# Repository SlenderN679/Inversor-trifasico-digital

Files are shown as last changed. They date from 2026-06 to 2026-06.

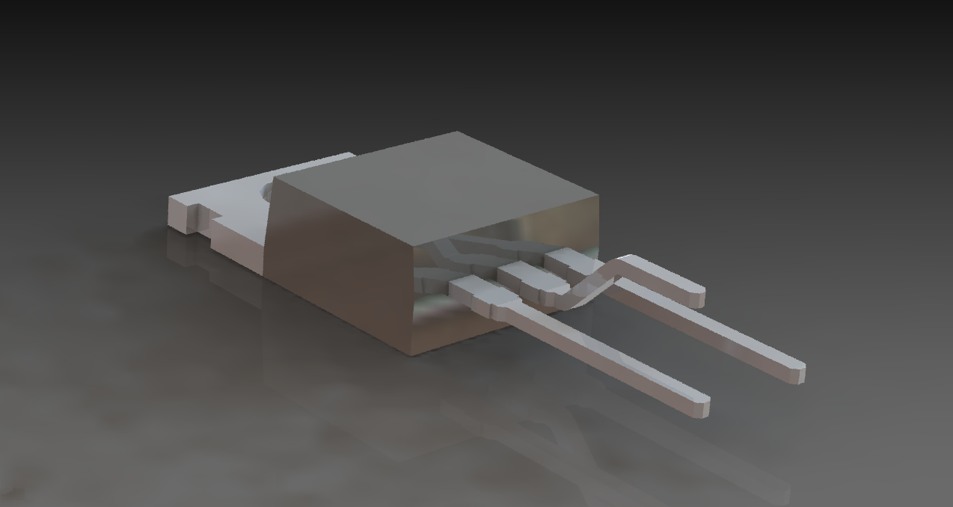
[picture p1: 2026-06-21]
Hardware/to-220-6.snapshot.1/5.PNG

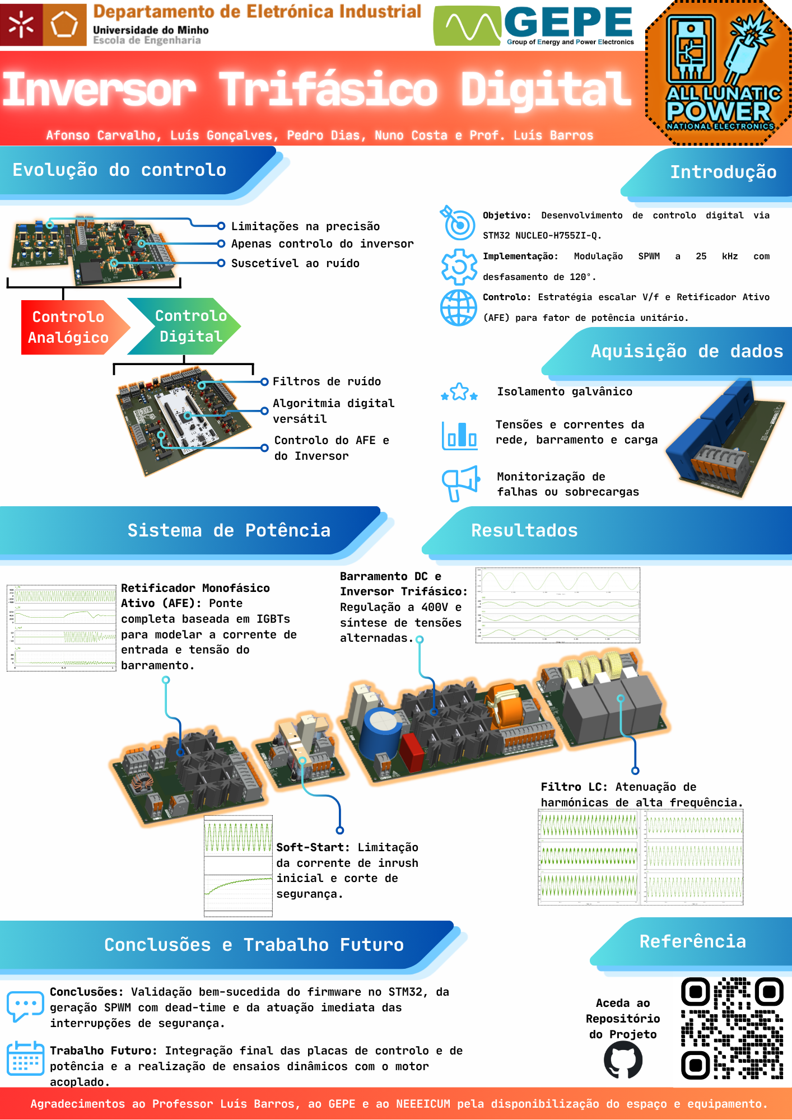
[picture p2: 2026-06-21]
Documentação/Poster.png

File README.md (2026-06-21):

# Inversor Trifásico com Controlo Digital ⚡





## 📌 Sobre o Projeto
Este repositório contém o firmware, o desenho de hardware e as simulações referentes ao desenvolvimento de um **Inversor Trifásico com Controlo Digital**, concebido no âmbito da disciplina de Projeto Integrador. 

O objetivo principal deste sistema é ultrapassar as limitações dos sistemas de controlo analógico (como a suscetibilidade ao ruído e restrições na precisão), transferindo a lógica de comutação e modulação para o domínio digital através de um microcontrolador **STM32 NUCLEO-H755ZI-Q**.

## ✨ Características Principais
* **Retificador Ativo (AFE):** Regulação de tensão num barramento de 400V DC com fator de potência unitário.
* **Inversor Trifásico:** Modulação por Largura de Pulso Sinusoidal (SPWM) operando a uma frequência de 25 kHz com injeção de *dead-time* por hardware.
* **Controlo de Motor:** Estratégia de controlo escalar (V/f constante) para regulação estável da velocidade angular.
* **Arranque Suave (Soft-Start):** Circuito de mitigação de correntes de *inrush* na pré-carga do barramento DC.
* **Telemetria:** Monitorização remota de dados (tensões, correntes e temperatura) via UART em formato JSON, integrada numa *dashboard* Node-RED.

## 📂 Estrutura do Repositório

| Diretório | Descrição |
| :--- | :--- |
| `Firmware/` | Código-fonte em C/C++ desenvolvido para o microcontrolador STM32H755ZI-Q (projeto STM32CubeIDE). |
| `Hardware/` | Ficheiros de desenho KiCad (esquemáticos, layout da PCB e ficheiros Gerber) das placas de controlo e potência. |
| `Simulacoes/` | Esquemas e testes dinâmicos criados no software PSIM para validação teórica dos blocos de potência. |
| `Telemetria/` | Ficheiros de configuração JSON para a interface gráfica no Node-RED. |
| `Documentacao/` | Relatório técnico completo, *datasheets* de componentes e o cartaz académico do projeto. |

## 🛠️ Tecnologias e Ferramentas Utilizadas
* **Hardware Digital:** Microcontrolador STMicroelectronics STM32 NUCLEO-H755ZI-Q.
* **Sensores e Isolamento:** Transdutores de corrente e tensão e *gate drivers* optoacoplados HCPL-3120.
* **Software/Ambientes:** STM32CubeIDE, KiCad EDA, PSIM, Node-RED.

## ⚠️ Aviso de Segurança
**PERIGO - ALTA TENSÃO:** Este projeto lida com tensões perigosas (entrada da rede elétrica e barramento DC de 400V). A replicação física e os testes na fase de potência requerem equipamento de proteção adequado e a supervisão de profissionais qualificados. Certifique-se de que os condensadores do barramento estão totalmente descarregados antes de manusear as placas.

## 👥 Equipa e Agradecimentos
**Desenvolvedores:** Afonso Carvalho, Pedro Dias, Luís Gonçalves e Nuno Costa.
**Orientação:** Prof. Luís Barros

Projeto desenvolvido com o apoio do **GEPE** (Grupo de Eletrónica de Potência e Energia) e do **NEEEICUM** (Núcleo de Estudantes de Engenharia Eletrónica Industrial e Computadores) da Universidade do Minho, Guimarães.

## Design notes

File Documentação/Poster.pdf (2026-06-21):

# Inversor Trifásico Digital

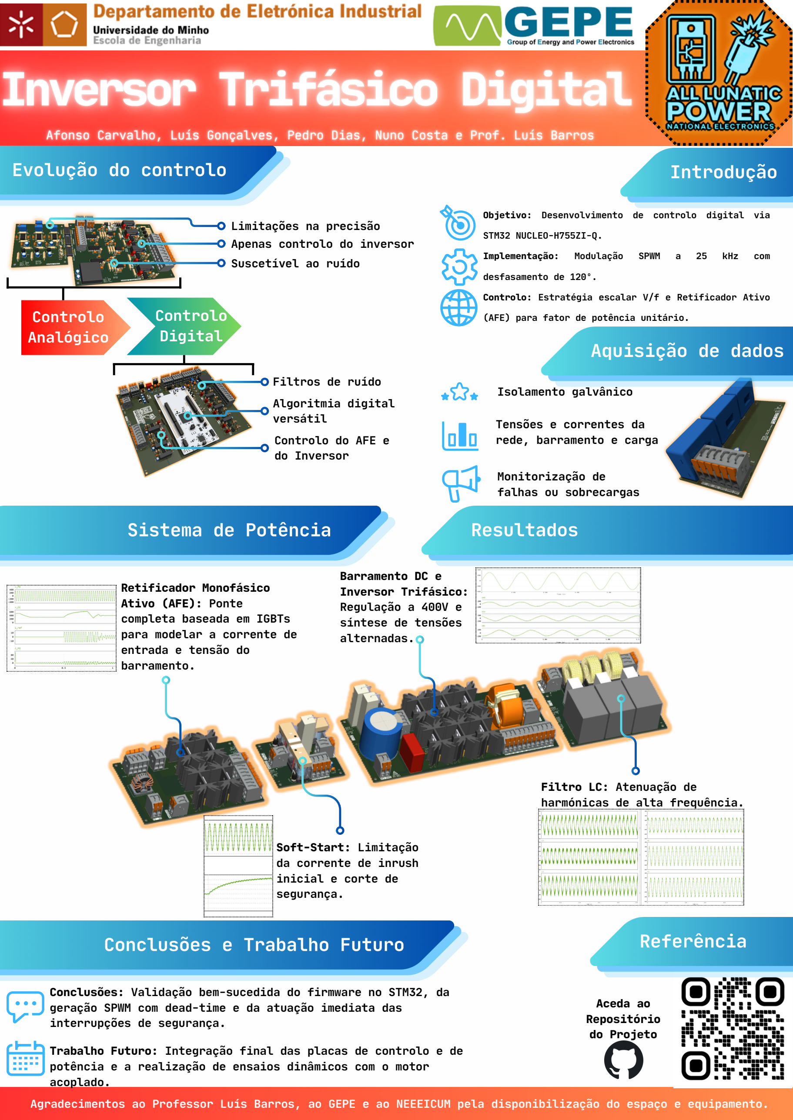
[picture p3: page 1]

Agradecimentos ao Professor Luís Barros, ao GEPE e ao NEEEICUM pela disponibilização do espaço e equipamento.

## Controlo Analógico

## Controlo Digital

Afonso Carvalho, Luís Gonçalves, Pedro Dias, Nuno Costa e Prof. Luís Barros

Objetivo: Desenvolvimento de controlo digital via

STM32 NUCLEO-H755ZI-Q.

Implementação: | Modulação | SPWM | a | 25 | kHz | com

desfasamento de 120º

Controlo: Estratégia escalar V/f e Retificador Ativo

(AFE) para fator de potência unitário.

Limitações na precisão
Apenas controlo do inversor Suscetível ao ruído

Algoritmia digital
versátil

Filtros de ruído

Controlo do AFE e
do Inversor

Isolamento galvânico

Tensões e correntes da
rede, barramento e carga

Monitorização de
falhas ou sobrecargas

Retificador Monofásico
Ativo (AFE): Ponte
completa baseada em IGBTs
para modelar a corrente de entrada e tensão do
barramento.

Soft-Start: Limitação
da corrente de inrush
inicial e corte de
segurança.

Barramento DC e
Inversor Trifásico:
Regulação a 400V e
síntese de tensões
alternadas.

Filtro LC: Atenuação de
harmónicas de alta frequência.

Conclusões: Validação bem-sucedida do firmware no STM32, da geração SPWM com dead-time e da atuação imediata das interrupções de segurança.

Trabalho Futuro: Integração final das placas de controlo e de potência e a realização de ensaios dinâmicos com o motor acoplado.

Aceda ao
Repositório
do Projeto

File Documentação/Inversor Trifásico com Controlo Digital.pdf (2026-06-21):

# Inversor Trifásico com Controlo Digital

Afonso Carvalho
Universidade do Minho
Braga, Portugal
a107058@alunos.uminho.pt

Pedro Dias
Universidade do Minho
Braga, Portugal
a106048@alunos.uminho.pt

Luís Gonçalves
Universidade do Minho
Ermesinde, Portugal
a108944@alunos.uminho.pt

Nuno Costa
Universidade do Minho
Guimarães, Portugal
a107069@alunos.uminho.pt

Luís Barros (Professor
Orientador)
GEPE (Grupo de
Eletrónica de Potência e
Energia) – Universidade do Minho
Guimarães, Portugal
lbarros@dei.uminho.pt

Resumo - Este artigo descreve o controlo digital de um inversor trifásico via STM32H755, implementando o SPWM (modulação por largura de pulso sinusoidal), o controlo V/f e o Retificador Ativo (AFE – front-end ativo). Simulações e ensaios a tensão reduzida validaram com sucesso o firmware, o condicionamento analógico e as proteções, comprovando a prontidão da unidade para integração de potência.
Palavras-chave - Inversor Trifásico, VFD (variador de frequência), Controlo Digital, STM32, SPWM, Retificador Ativo (AFE), Controlo Escalar V/f, Eletrónica de Potência.

### I. Introdução

A. Contextualização e Estado da Arte
O acionamento e o controlo da velocidade de motores trifásicos a partir de redes de alimentação monofásicas constituem um desafio técnico frequente em instalações elétricas onde a rede trifásica não está disponível. Tradicionalmente, recorre-se a sistemas de conversão de frequência constituídos por uma etapa de retificação e uma etapa de inversão. No mercado atual, as soluções industriais de variadores de frequência baseiam-se em circuitos eletrónicos que realizam o controlo digital das comutações dos interruptores de potência, assegurando maior flexibilidade de operação.

No âmbito da disciplina de Projeto Integrador 1, desenvolveu-se um protótipo de inversor trifásico com controlo analógico [3], onde a geração das formas de onda e a modulação por largura de pulso (PWM) eram efetuadas por componentes discretos. Contudo, os sistemas analógicos apresentam restrições na precisão, na imunidade ao ruído eletromagnético e na capacidade de executar funções dinâmicas complexas. Pretende-se resolver o problema central destas limitações através do desenvolvimento de uma plataforma de controlo assente no domínio digital.

B. Proposta de Resolução e Objetivos
Para ultrapassar as restrições identificadas no sistema analógico do semestre anterior, propõe-se o desenvolvimento e a implementação de uma arquitetura de controlo digital para o inversor trifásico. Esta abordagem permite transferir toda a lógica de comutação e modulação para um microcontrolador (STM32 NUCLEO-H755ZI-Q), o que expande a capacidade de processamento do sistema. A flexibilidade do controlo digital facilita a integração de rotinas de amostragem de dados e a execução de algoritmos corretivos em tempo real. Os objetivos estabelecidos para o projeto são apresentados em seguida:
- Desenvolvimento de um algoritmo digital para a modulação PWM trifásica com desfasamento preciso de 120 graus entre as fases operacionais;
- Implementação de uma malha fechada de controlo para a regulação estável da velocidade angular do motor trifásico;
- Integração de rotinas digitais de proteção contra sobrecorrentes e sobretensões no barramento de corrente contínua;
- Configuração de uma interface de operação para a monitorização em tempo real das variáveis do circuito.
C. Organização do Documento
O presente documento está estruturado em seis capítulos principais distintos (incluindo este) que descrevem as etapas de projeto e implementação. No Capítulo 2 [p.1], é apresentada a arquitetura global do sistema através de diagramas de blocos, detalhando os conceitos teóricos e a algoritmia associada ao controlo digital. O Capítulo 3 [p.3] é dedicado à exposição e análise dos resultados obtidos por intermédio de simulações computacionais do circuito eletrónico. No Capítulo 4 [p.5], é abordado o desenvolvimento do protótipo experimental, com a descrição detalhada dos periféricos do hardware utilizados. Os testes práticos e as respetivas análises de desempenho em ambiente laboratorial são apresentados no Capítulo 5 [p.8]. Por fim, no Capítulo 6 [p.9], são expostas as conclusões finais inferidas a partir do trabalho e as propostas de linhas de desenvolvimento para trabalho futuro.

### II. Arquitetura, conceitos e metodologias

A. Arquitetura Global do Sistema
O sistema proposto consiste na evolução de um conversor de frequência de controlo analógico para uma plataforma assente num microcontrolador de alto desempenho. A arquitetura global do conversor divide-se em duas secções fundamentais: o circuito de potência, responsável pela conversão e transferência de energia elétrica e o circuito de controlo digital, encarregue da aquisição de sinais, processamento algorítmico e atuação. Esta transição para o domínio digital permite a implementação de estratégias de controlo avançadas, como o controlo escalar de tensão e frequência (V/f) e a regulação ativa do lado da rede através da retificação controlada.
B. Diagrama de blocos do circuito de controlo
A “inteligência” do inversor reside no circuito de controlo, centralizado na placa de desenvolvimento STM32 NUCLEO-H755ZI-Q. A arquitetura deste bloco divide-se nas seguintes unidades funcionais, representadas na [Figura 1]:
- Módulo de Aquisição de Sensores: O microcontrolador faz a leitura contínua do estado físico do sistema através dos seus conversores analógico-digitais (Analog-to-Digital Converters – ADC) internos (ADC1 e ADC3). Foram monitorizadas variáveis críticas como a tensão e a corrente da rede de corrente alternada (ca), a tensão do barramento de corrente contínua (cc), as correntes das fases do motor (fases A, B e C) e a temperatura dos dissipadores de calor.
- Atuadores e Isolamento Galvânico: Os comandos lógicos do microcontrolador são transmitidos para a secção de potência através de gate drivers com isolamento galvânico ótico. Os temporizadores avançados (TIM1 e TIM8) do STM32 geram os sinais PWM para comandar respetivamente o retificador monofásico ativo (AFE) e o inversor trifásico.
- Painel de Controlo Local e Arrefecimento: A interface física com o utilizador foi realizada por um pequeno ecrã[5] e um encoder rotativo, comunicando com o processador pelo protocolo I2C e através do temporizador TIM4 (configurado em modo encoder). Em paralelo, um temporizador dedicado (TIM3) ajusta
ativamente | o | duty-cycle | das | ventoinhas | de
arrefecimento em função da temperatura lida nos dissipadores.
- Interface e Telemetria Remota: O sistema conta com uma monitorização remota através da transmissão de dados codificados em formato JavaScript Object Notation (JSON) por comunicação série UART (Receptor/Transmissor Assíncrono Universal). Estes dados alimentam uma interface gráfica construída no software Node-RED (acessível pelo navegador Web)[18], permitindo a supervisão remota das variáveis.
C. Algoritmia e metodologias de controlo
O software embebido que dita o comportamento do conversor é estruturado em três domínios principais: Gestão de Emergência, Domínio de Tempo Real e Domínio de Telemetria.
a) Domínio de Tempo Real e Controlo de Potência
O controlo do fluxo de energia exige um processamento rigoroso e determinístico. Para tal, configurou-se uma rotina de interrupção periódica a uma frequência de 25 kHz, gerida por um temporizador base. A cada ciclo desta interrupção, o sistema atualiza as leituras dos sensores e executa as lógicas de controlo do retificador e do inversor.
A modulação da ponte inversora recorre à técnica da SPWM, gerando três ondas de referência desfasadas exatamente 120 graus entre si. O algoritmo implementa um controlo escalar (V/f constante), ajustando a amplitude da tensão aplicada ao motor de forma estritamente proporcional à frequência desejada, com o intuito de manter o fluxo magnético da máquina constante ao longo de toda a rampa de aceleração.
b) Máquina de Estados do Retificador Ativo (AFE)
A operação segura do lado da rede é governada por uma máquina de estados finitos executada no domínio de tempo real:
- Estado 0 (Standby): O sistema permanece inativo, com os sinais PWM desativados e o relé de pré-carga (circuito de soft-start) aberto.
- Estado 1 (Pré-carga): Ocorre a retificação passiva inicial (através dos díodos antiparalelo dos IGBTs do AFE) para carregar gradualmente o barramento cc, protegendo os condensadores da corrente de inrush elevada. A transição para o estado seguinte ocorre quando a tensão lida no barramento ultrapassa um limiar de segurança pré-definido, momento no qual o microcontrolador ativa o relé de soft-start para curto-circuitar as resistências limitadoras.
- Estado 2 (Retificação Ativa): Inicia-se o controlo em malha fechada. O sistema utiliza uma malha de controlo do tipo Proporcional-Integral (PI) para anular o erro de tensão no barramento cc, gerando uma referência de potência. Seguidamente, um controlo direto por histerese (Bang-Bang) comuta os braços da ponte ativamente para que a corrente de entrada siga a referência ditada pela rede (sincronizada através de uma malha de captura de fase, ou Ciclo de Travagem da fase - PLL), garantindo um fator de potência unitário.
c) Proteções e Telemetria
A integridade do equipamento é assegurada por mecanismos de proteção acionados por hardware e software. Se a tensão do barramento exceder o limite máximo operacional estipulado; a corrente nas fases do motor ultrapassar as margens nominais de segurança ou a temperatura dos dissipadores atingir níveis críticos, é ativada uma rotina de emergência.
A velocidade do sistema de arrefecimento é gerida dinamicamente: as ventoinhas permanecem desligadas para

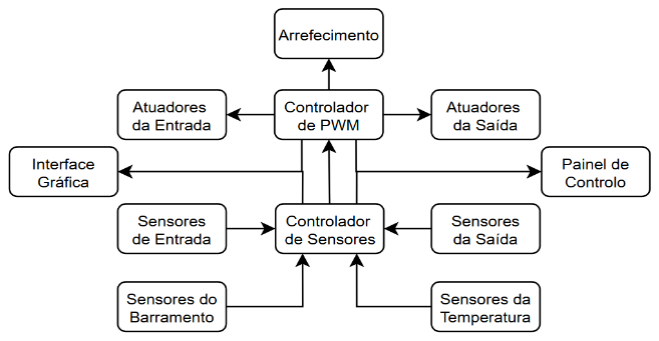
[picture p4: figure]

Figura 1 - Diagrama de blocos do circuito de controlo.

temperaturas reduzidas e atuam a 100 % da sua capacidade a partir de um limite estipulado, assumindo um comportamento linear no intervalo intermédio.
Fora do domínio crítico de tempo real, uma rotina executada a uma cadência de 10 Hz trata da atualização do ecrã local e do empacotamento das variáveis de telemetria para a transmissão em direção à plataforma Node-RED 10[17].
D. Diagrama de blocos do circuito de potência
O circuito de potência é responsável por efetuar a conversão de energia elétrica proveniente da rede monofásica de corrente alternada (ca) de forma a alimentar a carga trifásica com tensão e frequência devidamente reguladas. Na [Figura 2] pode observar-se a arquitetura e a organização estrutural deste circuito, a qual se divide nos sub-blocos lógicos que efetuam o processamento ordenado da energia.
A constituição e a funcionalidade de cada bloco do sistema que integra o circuito de potência são detalhadas em seguida:
- Rede Elétrica Monofásica: Constitui a fonte de alimentação primária de ca do sistema, fornecendo uma tensão nominal de 230 V com uma frequência de 50 Hz.
- Transformador de entrada: Posicionado à entrada do circuito com o intuito de alterar a tensão para a necessária para o motor e para garantir o correto isolamento do sistema.
- Retificador Monofásico Ativo: Consiste numa ponte completa monofásica totalmente controlada (AFE), baseada em quatro transístores bipolares de porta isolada (IGBTs). Este bloco modela ativamente a corrente de entrada para que apresente um perfil sinusoidal em fase com a tensão da rede, permitindo obter um fator de potência unitário e mitigar a distorção harmónica total (THD).
- Circuito de Soft-Start: Atua na fase inicial de ativação do sistema, tendo como função mitigar a elevada corrente de inrush (inrush current) que surge ao carregar os condensadores do barramento cc a partir do estado descarregado. Limita esta corrente inicial através de resistências de amortecimento, as quais são curto-circuitadas por um relé eletromecânico assim que o barramento atinge um nível de tensão seguro.
- Barramento de Corrente Contínua (DC-Link): Atua como o elemento de ligação, desacoplamento e armazenamento intermédio entre as etapas de retificação e inversão (barramento cc ou DC-Link). Este bloco inclui condensadores eletrolíticos de elevada capacidade destinados a filtrar as oscilações de tensão (ripple) e a estabilizar o barramento cc num patamar de tensão contínua predefinido de acordo com as especificações do projeto, dependendo das condições da rede e da carga.
- Inversor Trifásico: É composto por uma ponte trifásica constituída por seis IGBTs dispostos em três braços independentes. A partir da tensão contínua do barramento cc, este bloco sintetiza um sistema de tensões alternadas trifásicas através da aplicação do PWM bipolar.
- Filtro LC de Saída: Filtro passa-baixo trifásico constituído por indutâncias em série e condensadores em paralelo em cada uma das três fases de saída do inversor. A sua integração atenua de forma eficaz as
componentes | harmónicas | de | alta | frequência
decorrentes | da | comutação | PWM dos IGBTs,
suavizando as formas de onda de modo a entregar tensões e correntes com um perfil marcadamente sinusoidal à carga.
- Motor Trifásico: Representa a carga mecânica final do sistema, consistindo num motor de indução trifásico cuja velocidade angular e binário serão controlados de forma dinâmica através da variação proporcional da amplitude e da frequência das tensões aplicadas pela etapa inversora filtrada.

### III. Simulações computacionais

Neste capítulo, apresentam-se as simulações computacionais realizadas no software PSIM com o objetivo de validar o correto funcionamento das malhas do sistema. Os ensaios focam-se na análise do desempenho em regime permanente tanto do Retificador Ativo (AFE) como do Inversor Trifásico, fundamentando a transição segura para a etapa de implementação física.

A. Retificador passivo
Para a validação do algoritmo do AFE, geramos uma simulação [Figura 3] onde a carga do retificador varia, de modo a validar a estabilidade da tensão do barramento cc.

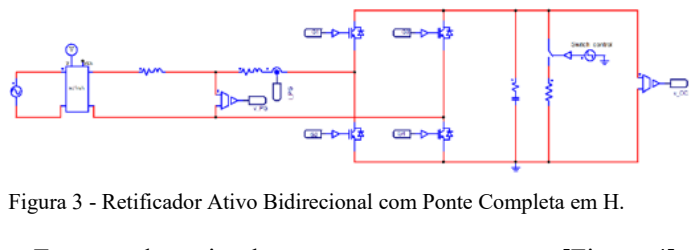
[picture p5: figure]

Executando a simulação com carga constante [Figura 4], confirma-se a regulação da tensão no valor nominal de 400 V projetado, apresentando um ripple residual praticamente nulo.

Figura 2 - Diagrama de blocos do sistema.

Figura 3 - Retificador Ativo Bidirecional com Ponte Completa em H.

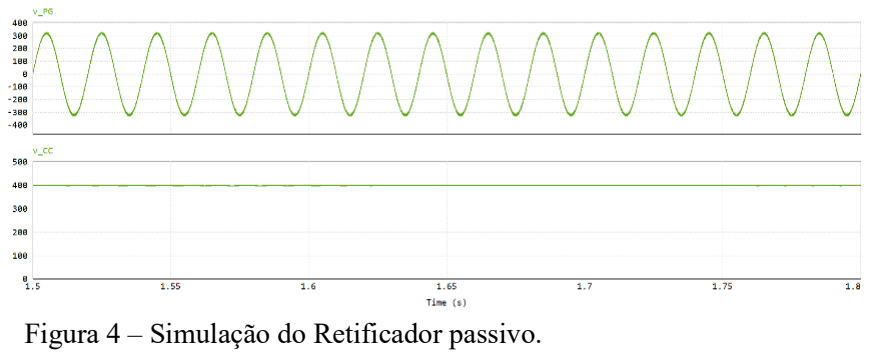
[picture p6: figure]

Figura 4 – Simulação do Retificador passivo.

A [Figura 5] mostra o comportamento do retificador ativo perante uma variação de carga em t = 0.5s. Observa-se que o barramento cc, após uma perturbação transitória, recupera para o valor de referência de 400 V, demonstrando a capacidade de regulação do controlador. A referência de corrente (i_ref), gerada pelo regulador de tensão, aumenta automaticamente após a variação de carga, forçando o retificador a absorver mais energia da rede para compensar o aumento de consumo. A corrente absorvida da rede (i_PG) acompanha esta referência, mantendo uma forma sinusoidal e em fase com a tensão da rede, confirmando o funcionamento com fator de potência unitário.

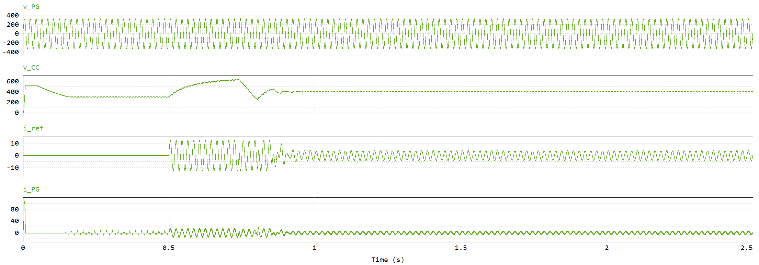
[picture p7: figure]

B. Inversor trifásico
Com a segunda simulação [Figura 6], tencionamos validar o acionamento correto dos IGBTs, de forma a gerar sinais sinusoidais, desfasados por 120º e que não sofram de shoot-through nos ramos da ponte.

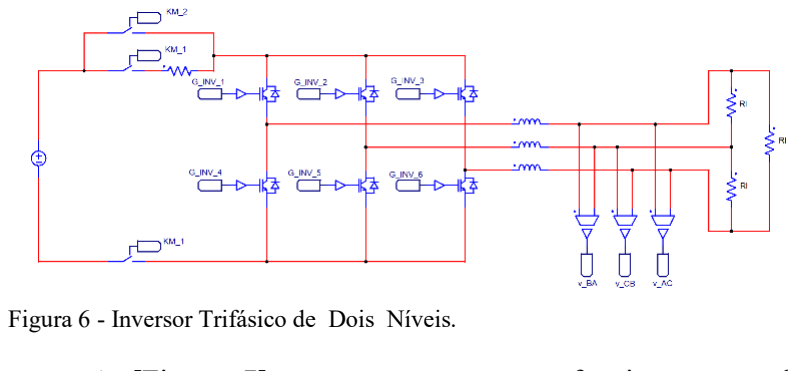
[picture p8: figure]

A [Figura 7] comprova o correto funcionamento do inversor trifásico através da obtenção das três tensões de linha aplicadas à carga, as quais apresentam o perfil retangular simétrico característico da modulação SPWM a 25 kHz com amplitudes equilibradas e desfasadas 120º entre si.

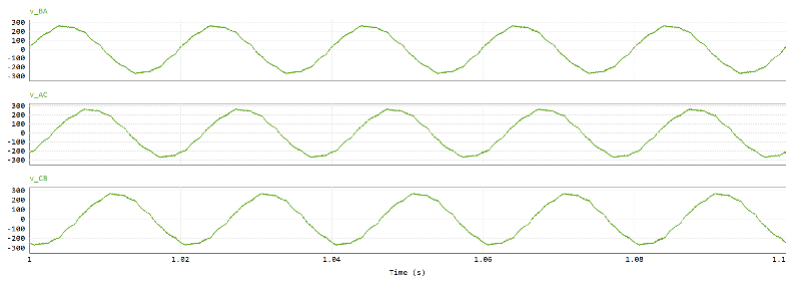
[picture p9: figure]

C. Filtro LC
Para melhorar a qualidade do sinal de saída, testamos um filtro passa-baixo trifásico [Figura 8], baseado na ressonância de um indutor e condensador, que eliminará as frequências superiores à ressonante do par. Testamos ainda uma resistência em série com o condensador, de forma a amortecer a resposta à frequência de corte do filtro.

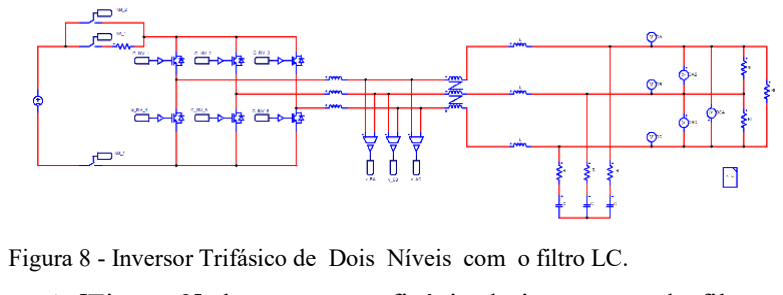
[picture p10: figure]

A [Figura 9] demonstra a eficácia da integração do filtro LC passa-baixo à saída do inversor, demonstrando a atenuação do ruído de alta frequência da comutação e a consequente obtenção de três tensões sinusoidais limpas.

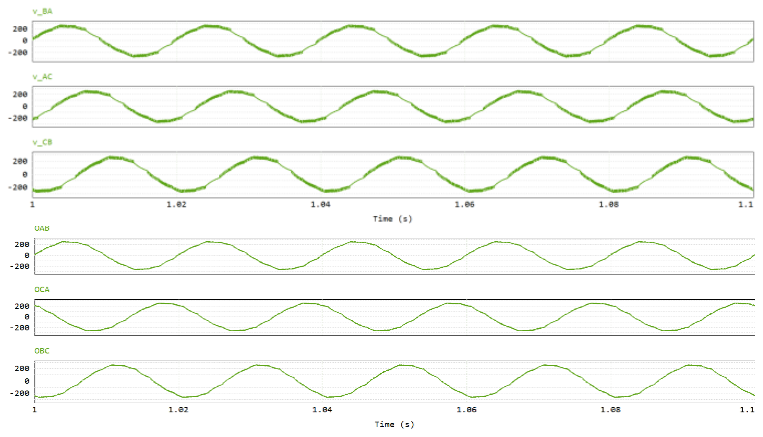
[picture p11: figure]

D. Sistema completo
Por fim, combinamos as simulações numa só [Figura 10] para validar a interação entre os elementos e o correto funcionamento que desejamos com este projeto.

A [Figura 11] valida a estabilidade e o correto funcionamento integrado de todo o controlador, demonstrando que a operação conjunta do Retificador Ativo (AFE) e do Inversor Trifásico em regime permanente, com a inclusão do filtro LC, garante a obtenção de tensões sinusoidais, equilibradas e desfasadas 120º na carga.

Figura 9 - Tensão antes e depois do filtro.

Figura 10 - Sistema completo.

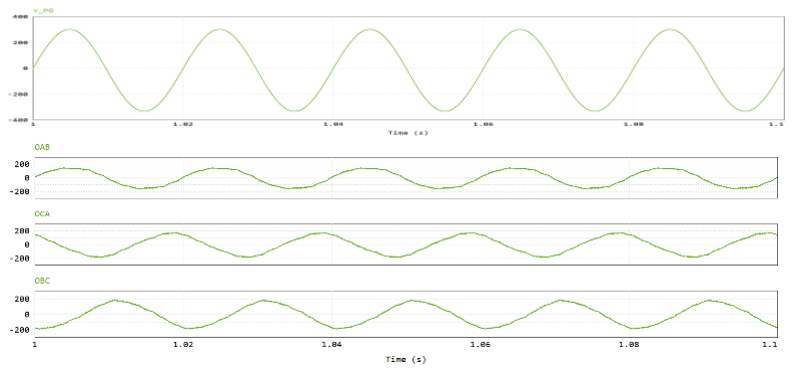
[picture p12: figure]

Figura 11- Tensões de entrada e saída.

Figura 8 - Inversor Trifásico de Dois Níveis com o filtro LC.

Figura 5 - Simulação do Retificador Ativo.

Figura 6 - Inversor Trifásico de Dois Níveis.

Figura 7 - Simulação do inversor.

### IV. Desenvolvimento do protótipo experimental

Neste capítulo é apresentada a implementação física e o desenvolvimento do hardware do protótipo experimental do inversor projetado. Nas secções seguintes detalham-se os esquemáticos elétricos, as estratégias de desenho de circuito impresso (PCB) e a identificação dos periféricos e componentes críticos utilizados.

A. Arquitetura Geral do Protótipo
O protótipo é constituído por dois blocos eletricamente isolados para garantir a segurança da eletrónica de processamento de sinal face aos elevados níveis de tensão e corrente da etapa de potência:
1. Módulo de Controlo Digital [Figura 12]: Responsável pelo processamento dos algoritmos de controlo, geração dos sinais PWM e leitura de sensores.

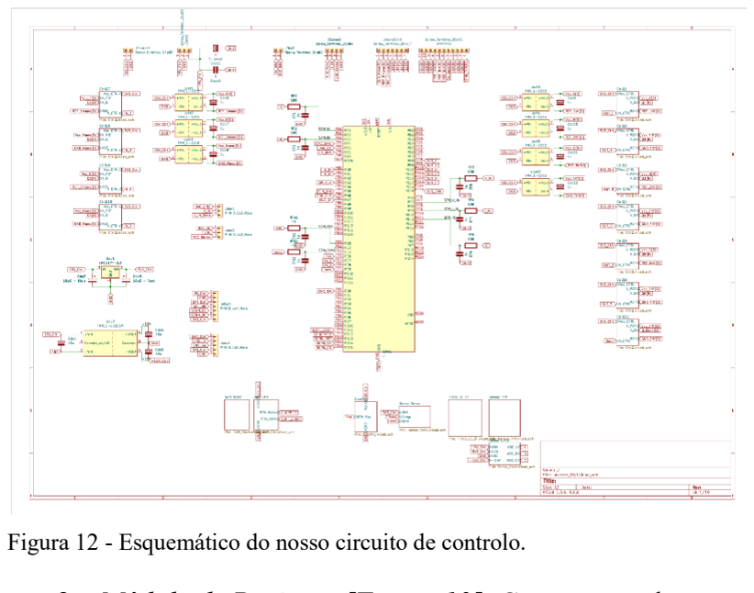
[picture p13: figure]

2. Módulo de Potência [Figura 13]: Composto pela ponte inversora, barramento de corrente contínua (cc), filtragem de saída e circuitos de proteção/pré-carga.

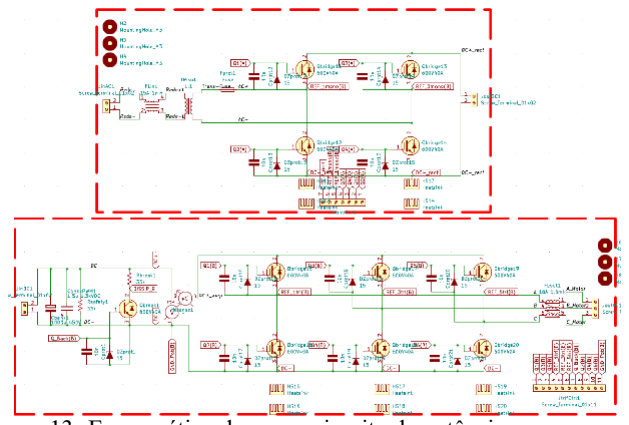
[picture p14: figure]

B. Circuito de Controlo Digital e Condicionamento Esta secção descreve a eletrónica de baixa tensão dedicada ao processamento e isolamento de sinais.
a) Isolamento galvânico e drivers da gate
Para realizar a interface entre os pinos de saída do microcontrolador (níveis lógicos de 3,3 V / 5 V) e os terminais de gate dos interruptores de potência, foram implementados drivers isolados [Figura 14] baseados no circuito integrado HCPL-3120.
- Princípio | de | Funcionamento: | O | HCPL-3120
providencia isolamento galvânico através do opto acoplador e possui uma capacidade para fornecer correntes de pico elevadas (até 2,5 A), necessárias para carregar e descarregar rapidamente as capacidades parasitas de gate dos IGBTs.
- Componentes de Apoio: Junto a cada driver, utilizou-se uma resistência de gate em série (Rg = 22 Ω) para amortecer oscilações e controlar a velocidade de comutação (di/dt e dv/dt), e uma resistência de descarga gate-source (Rgs = 10 kΩ) para garantir que o interruptor se mantém cortado na ausência de sinal de comando. O desacoplamento local da alimentação do driver é assegurado por um condensador de 0,1 μF.

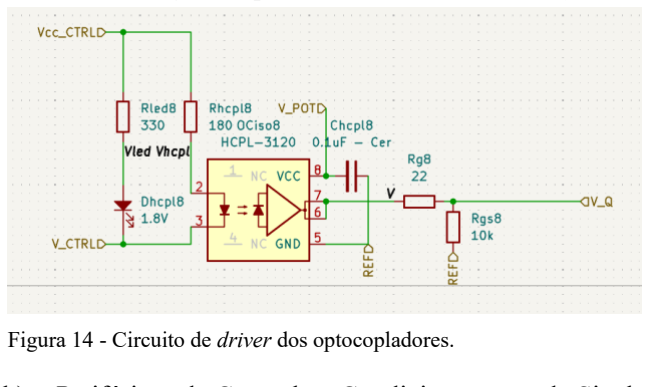
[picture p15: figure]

b) Periféricos de Controlo e Condicionamento de Sinal Para além dos andares de isolamento e condução de porta (gate drivers) detalhados anteriormente, o sistema de controlo digital do inversor exige uma infraestrutura periférica complexa. Esta subsecção descreve os circuitos analógicos de aquisição de dados, proteção e gestão de potência auxiliar necessários para garantir a operação segura e precisa do STM32.
i. Circuito de Sensores Trifásico e Condicionamento do Sinal
A correta execução dos algoritmos de controlo de corrente e sincronização da rede através do PLL depende criticamente da qualidade dos sinais analógicos injetados no conversor analógico-digital (ADC) do microcontrolador.
- Aquisição Isolada [Figura 15]: A medição das correntes/tensões do sistema é efetuada recorrendo a transdutores de efeito Hall de alta precisão (como o modelo LA100-P). Estes sensores fornecem um isolamento galvânico total entre o circuito de potência e o circuito de controlo, convertendo a grandeza medida numa corrente secundária proporcional. Esta corrente é posteriormente convertida em tensão através de uma resistência de carga (burden resistor).

Figura 13- Esquemático do nosso circuito de potência.

Figura 12 - Esquemático do nosso circuito de controlo.

Figura 14 - Circuito de driver dos optocopladores.

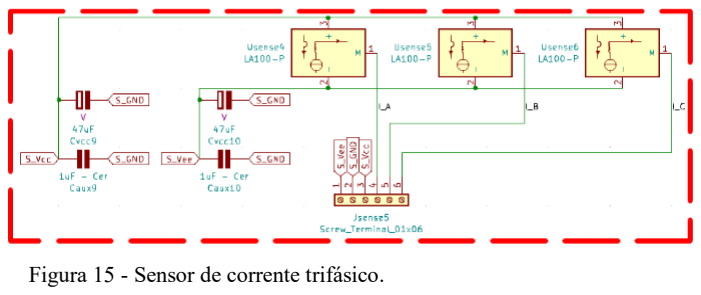
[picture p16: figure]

- Condicionamento Analógico [Figura 16]: Uma vez que os pinos de leitura do STM32 possuem uma gama dinâmica estrita (tipicamente de 0 V a 3,3 V), os sinais provenientes dos sensores passam por um andar de condicionamento. Este bloco ajusta o ganho do sinal e introduz um desvio contínuo (offset de tensão), garantindo que os sinais sinusoidais alternados fiquem centrados em 1,65 V. Adicionalmente, são integrados
condensadores | de | desacoplamento | e | filtragem
analógica colocados junto à alimentação do bloco analógico para mitigar o ruído eletromagnético induzido pelas comutações de alta frequência dos IGBTs, atuando como um filtro anti-aliasing passivo.

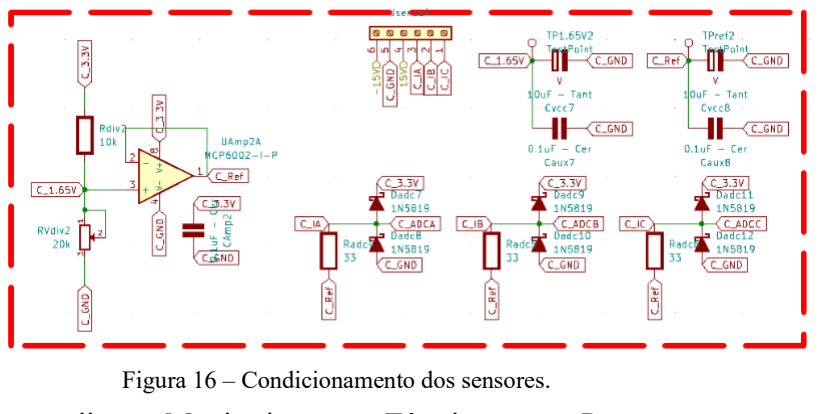
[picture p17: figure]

ii. | Monitorização | Térmica | e | Proteção | contra
Sobreaquecimento
A segurança dos semicondutores de potência é salvaguardada por um circuito dedicado à monitorização da temperatura do dissipador térmico:
- Elemento Detetor: Utiliza-se um termístor NTC (modelo NTCALUG02A103G), cuja resistência elétrica diminui de forma não-linear com o aumento da
| temperatura.
- Topologia de Leitura: O NTC está configurado numa topologia de divisor de tensão [Figura 17] alimentado por uma referência de tensão estável. A variação da tensão no nó intermédio do divisor é diretamente proporcional à variação térmica.

iii. Sistema de Arranque Suave e Circuito de Pré-Carga Aquando da ligação inicial do inversor à fonte de alimentação, o banco de condensadores de elevada capacidade do barramento cc comporta-se momentaneamente como um curto-circuito virtual. Para evitar uma corrente de pico destrutiva (inrush current) que danificaria a ponte retificadora ou os fusíveis de proteção, implementou-se um circuito de pré-carga composto por dois blocos:

- Andar de Potência (Soft_Start) [Figura 18]: O fluxo
| inicial da corrente é forçado a passar por resistências de potência limitadoras (Rsoft1 de 100 Ω). Estas resistências absorvem a energia transitória enquanto o banco de condensadores carrega de forma gradual e controlada.

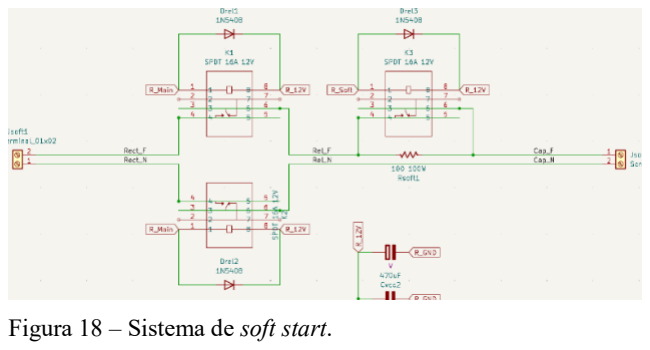
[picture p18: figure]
Figura 18 – Sistema de soft start.

- Interface de Comando [Figura 19]: Devido à necessidade de correntes de excitação mais elevadas para as bobinas dos relés, o sinal do STM32 é amplificado através de andares de comutação com transístores. Adicionalmente, são colocados díodos de roda-livre de rápida recuperação (como o 1N5408) em paralelo com as bobinas dos relés para suprimir os picos de sobretensão indutiva gerados no momento da desenergização das mesmas.
- Mecanismo de Bypass (Soft_Ctrl): Assim que a tensão do barramento cc atinge um limiar seguro próximo do valor nominal estável, o STM32 envia um sinal digital para atuar relés eletromecânicos de potência (Jrel2). Os contactos destes relés fecham, curto-circuitando as resistências de limitação e permitindo a passagem direta da corrente nominal com perdas mínimas.

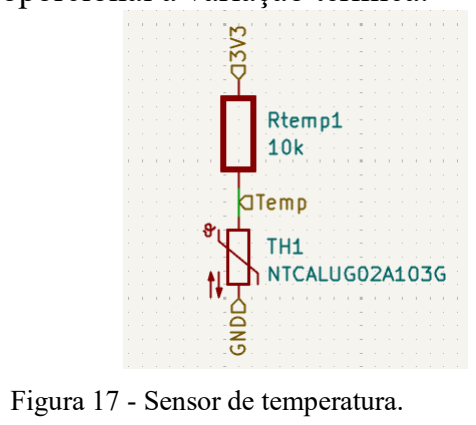
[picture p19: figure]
Figura 17 - Sensor de temperatura.

iv. Circuito de Gestão Térmica Ativa Para manter o perfil térmico do inversor dentro dos

limites operacionais ótimos, o sistema possui um circuito de controlo para ventilação forçada [Figura 20]:

- Controlo da Ventoinha: A ativação do motor cc da
| ventoinha é comandada por um sinal lógico digital

Figura 16 – Condicionamento dos sensores.

Figura 15 - Sensor de corrente trifásico.

Figura 19 - Sistema de soft control.

proveniente do STM32, atuando um interruptor eletrónico (MOSFET em modo de saturação/corte).
- Estabilização da Alimentação: Dado que as ventoinhas introduzem ruído elétrico significativo na calha de alimentação de controlo devido à comutação interna
dos | seus | motores | elétricos, | são | adicionados
condensadores eletrolíticos de filtragem de elevada capacidade (100 μF). Estes componentes atuam como um reservatório local de energia, estabilizando a linha de tensão auxiliar e prevenindo quedas abruptas de tensão que pudessem comprometer a estabilidade do microcontrolador durante o arranque da ventoinha.

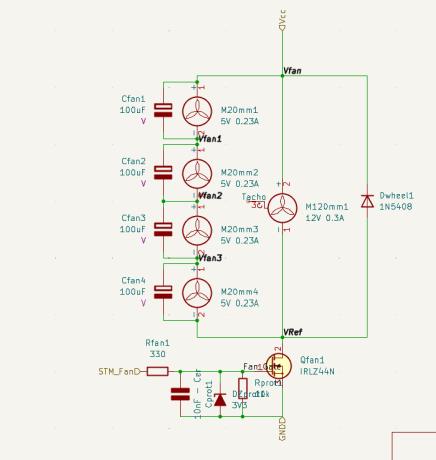
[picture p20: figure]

v. Filtragem dos sinais dos sensores
Um filtro passa-baixo passivo [Figura 21], constituído por uma resistência em série e um condensador em paralelo com o pino de entrada analógica do STM32, elimina quaisquer transientes ou ruídos espúrios, permitindo ao ADC ler os sinais puros.

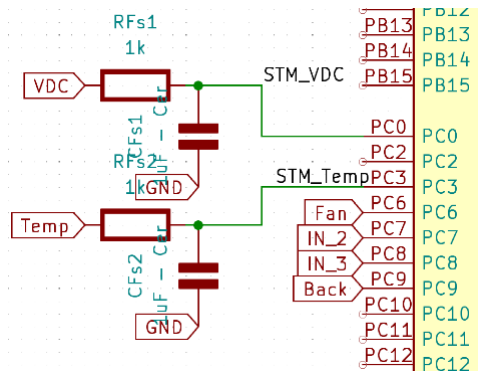
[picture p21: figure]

c) Desenho e Layout da PCB (Printed Circuit Board) O projeto dos circuitos impressos seguiu regras estritas de compatibilidade eletromagnética (EMC) e integridade de sinal:
- Separação Física e de massas: O layout da PCB de controlo e a de potência foram mantidos fisicamente independentes (ou isolados por barreiras físicas no plano), garantindo distâncias de isolamento adequadas para evitar arcos elétricos entre as pistas de alta tensão e os planos de baixa tensão.
- Dimensionamento das Pistas de Potência: As pistas condutoras por onde circulam as correntes principais da ponte inversora e do barramento cc [Figura 22] foram desenhadas com largura acrescida e planos de cobre espessos, de forma a minimizar a resistência óhmica, mitigar a queda de tensão e evitar o sobreaquecimento do material de FR4 (nome do material de que é feita a própria PCB).

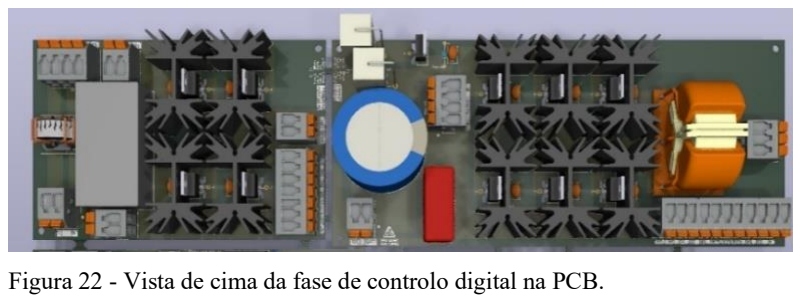
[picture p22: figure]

- Planos de Massa de Controlo: No PCB de controlo digital [Figura 23], utilizaram-se planos de massa contínuos nas camadas, para criar um caminho de retorno de baixa impedância para os sinais de alta frequência, minimizando a captação de ruído radiado pelas comutações abruptas dos IGBTs.

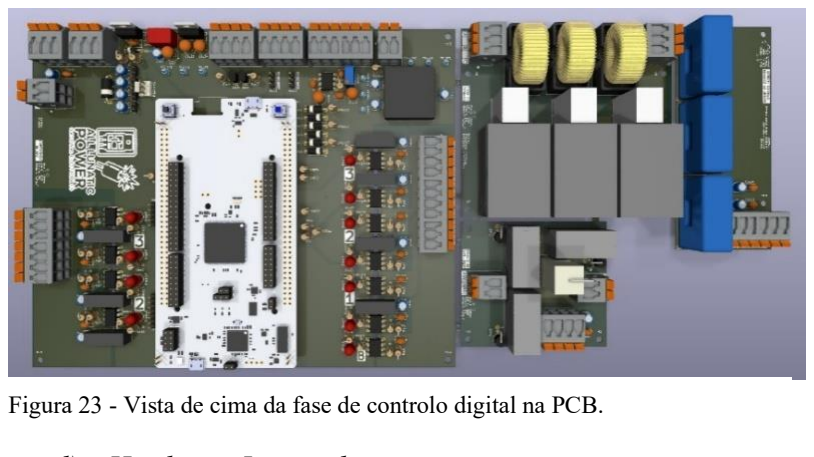
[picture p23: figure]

d) Hardware Integrado
A [Tabela 1] expõe a seleção do hardware fulcral do projeto.

Tabela 1 - Componentes Principais do Protótipo.

Componente | Referência | Função
Microcontrolador | NUCLEO-H755ZI-Q | Unidade Central de Controlo
Semicondutores de potência | IGBT 600 V 40 A | Comutação de potência na ponte AFE e no Inversor
Condensador de potência | 1000 µF 450 V | Armazenamento e estabilização de tensão no barramento cc
Optoacopladores | HCPL-3120 | Isolamento galvânico e comando dos IGBTs
Transdutores de corrente | LEM LA 100-P [8] | Leitura isolada das correntes de fase
Transdutor de tensão | CYHVS5-25A [4] | Leitura isolada das tensões da

Figura 20 - Sistema de arrefecimento.

Figura 21 - Filtro RC Passa-Baixo.

Figura 23 - Vista de cima da fase de controlo digital na PCB.

Figura 22 - Vista de cima da fase de controlo digital na PCB.

| | rede e do barramento
Termístor | NTCALUG02A 103G | Monitorização térmica dos dissipadores
Amplificador operacional | MCP6002-I-P | Condicionamento analógico de sinal e criação de massa virtual
Conversor DC-DC Isolado | MEV1S1505SC | Fornecimento de alimentação isolada para os gate drivers
Regulador Step-Down | TSR 1-2433 | Regulação limpa da malha lógica de 3.3V
Relé eletromagnético | SPDT 16 A 12 V | Bypass da resistência de Soft-Start e Corte do barramento
Indutor de filtro | 330 μH 3A | Elemento indutor do filtro LC ressonante
Condensador de filtro | 10 μF 310 V ca 630 V cc | Elemento capacitivo do filtro LC ressonante

### V. RESULTADOS EXPERIMENTAIS

O presente capítulo detalha a fase de validação experimental do protótipo desenvolvido. O ciclo de desenvolvimento de um inversor exige uma abordagem metodológica e faseada, priorizando a segurança e a estabilidade da lógica de comando. Por conseguinte, os ensaios laboratoriais aqui documentados foram realizados num ambiente de baixa tensão, aplicando uma entrada de 30 V ca à ponte retificadora.
Devido a constrangimentos logísticos externos na cadeia de fornecimento dos componentes de eletrónica de potência e aos prazos de fabrico da placa de circuito impresso (PCB) final, a validação física do sistema completo não foi possível. Esta metodologia de validação recorre a DACs e simulações em código, para emular o andar de potência, assim permitindo atestar a robustez da Unidade Central de Controlo (baseada no microcontrolador STM32H755) e o correto condicionamento de sinal, mitigando riscos de falhas catastróficas antes da transição para o regime de alta tensão.
A. Validação da Geração de Sinais de Controlo (SPWM)

O primeiro ensaio visou comprovar a correta síntese da SPWM gerada pelo microcontrolador [Figura 24]. A análise direta aos pinos de saída confirmou a estabilidade da frequência portadora definida a 25 kHz.

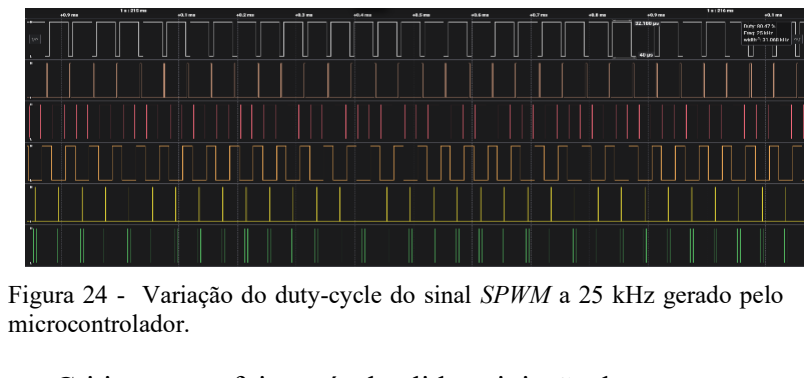
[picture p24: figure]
microcontrolador.

Criticamente, foi possível validar a injeção do tempo morto (dead-time) [Figura 25] gerado por hardware nos canais complementares. A medição entre o sinal High e Low de uma mesma fase comprovou a existência da margem de segurança temporal, garantindo que não ocorrerá condução simultânea (curto-circuito) nos IGBTs.

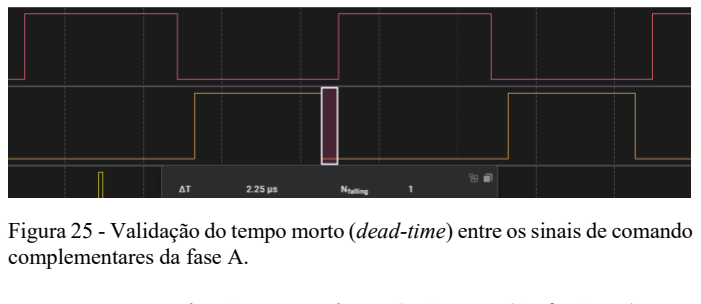
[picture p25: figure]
complementares da fase A.

B. Resposta do Circuito de Pré-Carga (Soft-Start)

Para evitar picos de corrente (inrush current) na energização dos condensadores do barramento cc, o sistema incorpora um circuito de arranque suave. Alimentando a placa a 30 V ca, monitorizou-se o comportamento temporal da tensão contínua.
A lógica de controlo demonstrou atuar em conformidade: o relé principal de bypass apenas foi acionado após o término do período de transição estipulado no código, altura em que o barramento atinge a estabilidade nominal para os ensaios, garantindo a integridade da ponte retificadora.
C. Aquisição Sensorial e Condicionamento (ADC)

A fiabilidade da malha de controlo depende inteiramente da precisão da leitura analógica. Nesta fase, validou-se o circuito de condicionamento de sinal desenhado para os transdutores fazerem interface com o ADC de 3,3 V do microcontrolador [Figura 26].
Verificou-se a estabilidade do referencial de tensão virtual ("massa virtual"), crucial para a leitura de sinais bipolares provenientes dos sensores de corrente.

Figura 24 - Variação do duty-cycle do sinal SPWM a 25 kHz gerado pelo

Figura 25 - Validação do tempo morto (dead-time) entre os sinais de comando

Adicionalmente, injetando sinais estáticos na calha de leitura térmica, confirmou-se a atenuação de ruído através do filtro passa-baixo RC (com frequência de corte projetada para bloquear interferências na banda dos kHz) e a correta conversão algorítmica pela FPU (Floating-Point Unit) do microcontrolador.

D. Lógica de Proteção e Resposta a Falhas

O culminar da validação experimental incidiu sobre a capacidade do firmware em proteger o drive. Foram simuladas anomalias por hardware [Figura 27], nomeadamente um possível curto-circuito num dos sensores instalados.
A arquitetura orientada a interrupções (Interrupts) do microcontrolador provou desativar instantaneamente todos os canais SPWM, cujos contactos utilizam lógica inversa (Vcc => OFF), forçando os gate drivers ao estado de corte no momento exato em que os limites de segurança foram ultrapassados, validando a fiabilidade da placa para operar com segurança em futuras iterações.

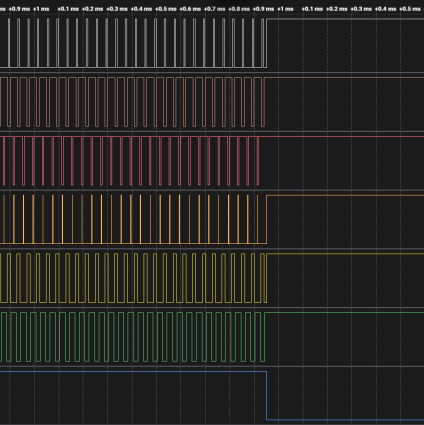
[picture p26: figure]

E. Globalidade do controlador
Por fim, testou-se a integração dos vários módulos de controlo para validar a sua interação em funcionamento. Devido à ausência da interface com andar de potência, utilizaram-se sinais gerados pelo DAC do STM32 para as tensões da rede e barramento e as correntes do motor foram simuladas digitalmente no código.

Observando os sinais apresentados na interface [Figura 28], foi possível confirmar o correto funcionamento do PLL a estabilizar o barramento cc, a rampa de aceleração do inversor e da gestão térmica do sistema.


### VI. Conclusões e trabalho futuro

O desenvolvimento deste projeto permitiu estruturar e validar a transição de uma arquitetura de controlo analógica para uma plataforma inteiramente gerida no domínio digital. A centralização da lógica no microcontrolador NUCLEO-H755ZI-Q revelou-se um sucesso do ponto de vista do software, permitindo a geração precisa da SPWM com injeção de dead-time por hardware, bem como a codificação de uma máquina de estados robusta para a gestão do Retificador Ativo (AFE) e do Soft-Start.
Importa salientar que, devido a atrasos logísticos imprevistos no fornecimento de componentes críticos e no fabrico da placa de circuito impresso (PCB), ainda não foram realizados testes físicos do sistema total integrado, sendo estes a prioridade quando se tiver a entrega dos componentes. A validação experimental documentada incidiu de forma exclusiva sobre a Unidade Central de Controlo e o respetivo firmware, visto que o andar de potência foi validado no semestre passado. Através da injeção de sinais e da análise de bancada, comprovou-se a eficácia do condicionamento do ADC e a atuação imediata das interrupções de segurança, garantindo que a unidade de processamento e os sinais de comando dos gate drivers (HCPL-3120) estão prontos para operar.
F. Trabalho Futuro
Estando o algoritmo de controlo validado de forma isolada, as etapas futuras centram-se inteiramente na integração física e no comissionamento do hardware:
a) Montagem e Integração Global:
Assemblagem da placa final desenhada no KiCad e união física/elétrica entre o módulo de controlo digital e o andar de potência.
b) Testes do Sistema Total (30 V ca):
Alimentar o inversor completo com a tensão de projeto de 30 V ca, após o transformador de isolamento, para validar em conjunto as comutações reais dos IGBTs, a carga do barramento cc (aos ~ 42 V) e a ausência de ruído eletromagnético cruzado entre as placas.

Figura 26 - Leitura dos ADCs observada na interface.

Figura 27 - Atuação da interrupção de segurança: corte instantâneo dos sinais SPWM perante a deteção de anomalia.

Figura 28 - Teste do controlador.

c) Ensaio Dinâmico com Carga:
Acoplar o inversor trifásico ao motor e proceder à sintonia empírica da malha de controlo V/f e do PLL em malha fechada.
d) Telemetria SCADA:
Finalizar a transmissão de pacotes JSON pela UART para a atualização em tempo real da dashboard gráfica estabelecida no Node-RED.

### VII. Agradecimentos

Os autores gostariam de expressar o seu profundo agradecimento ao Professor Luís Barros pela orientação técnica, disponibilidade e partilha de conhecimentos ao longo do desenvolvimento deste projeto no seio do Grupo de Eletrónica de Potência e Energia (GEPE) da Universidade do Minho.
Expressamos ainda a nossa sincera gratidão ao Núcleo de
Estudantes | de | Engenharia | Eletrónica | Industrial | e
Computadores (NEEEICUM) pela disponibilização de espaço físico e instrumentos de bancada, que viabilizaram a montagem, depuração e realização dos ensaios laboratoriais do protótipo de controlo. Por fim, agradecemos a todos os técnicos de laboratório e colegas que, direta ou indiretamente, contribuíram para a concretização deste trabalho.

### VIII. Referências bibliográficas

[1] Avago Technologies, "HCPL-3120/J312, HCNW3120: 2.5 Amp Output Current IGBT Gate Drive Optocoupler," Datasheet, 2008.
[2] L. A. M. Barros, "Smart Power Conditioners for Eletric Railway Power Grids," 2023.
[3] A. Carvalho, L. Gonçalves, N. Costa, and P. Dias, "Inversor trifásico," 2026.
[4] ChenYang Technologies, "Hall Effect Voltage Sensor CYHVS5-25A," Datasheet, 2016.
[5] L. Clark, "Adafruit 1.14" 240x135 Color Newxie TFT Display," Adafruit Industries, 2025.
[6] S. Golestan, J. M. Guerrero, and G. B. Gharehpetian, "Five Approaches to Deal With Problem of DC Offset in Phase-Locked Loop Algorithms: Design Considerations and Performance Evaluations," IEEE Transactions on Power Electronics, vol. 31, no. 1, pp. 648-661, Jan. 2016.
[7] M. Karimi-Ghartemani and M. R. Iravani, "A Method for Synchronization of Power Electronic Converters in Polluted and Variable-Frequency Environments," IEEE Transactions on Power Systems, vol. 19, no. 3, pp. 1263-1270, Aug. 2004.
[8] LEM, "Current Transducer LA 100-P," Datasheet, 2023.
[9] L. Louro, N. Ribeiro, and L. Barros, "Controlo Digital da Posição Angular de um Motor CC," 2026.
[10] R. S. Santos, "Retificador trifásico bidirecional com alto fator de potência aplicado à excitação de geradores síncronos," 2013.
[11] STMicroelectronics, "RM0399 Reference manual," 2023.
[12] STMicroelectronics, "STM32 Nucleo-144 boards," 2026.
[13] STMicroelectronics, "STM32H755xl," 2026.
[14] STMicroelectronics, "UM2408 User manual," 2025.
[15] X. Wang, M. G. Taul, H. Wu, Y. Liao, F. Blaabjerg, and L. Harnefors, "Grid-Synchronization Stability of Converter-Based Resources—An Overview," IEEE Open Journal of Industry Applications, vol. 1, pp. 115-134, 2020.
[16] Adafruit Industries, "Adafruit-ST7735-Library," GitHub
Repository. | [Online]. | Available:
https://github.com/adafruit/Adafruit-ST7735-Library.
[17] OpenJS Foundation, "Node-RED," Node-RED. [Online]. Available: https://nodered.org/.
[18] OpenJS Foundation, "Getting Started: Running locally,"
Node-RED | Documentation. | [Online]. | Available:
https://nodered.org/docs/getting-started/local.
[19] OpenJS Foundation, "User Guide: Working with nodes,"
Node-RED | Documentation. | [Online]. | Available:
https://nodered.org/docs/user-guide/nodes.

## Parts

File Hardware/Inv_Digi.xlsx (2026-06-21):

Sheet: Inv_Digi
Reference | Qty | Value | Price | Footprint | Datasheet | Cust | Stock | Need | Buy | Price | Cost | T.T
CAmp1,Caux5,Caux6,Chcpl1,Chcpl2,Chcpl3,Chcpl4,Chcpl5,Chcpl6,Chcpl7,Chcpl8,Chcpl9,Chcpl10,Chcpl11 | 14 | 0.1uF - Cer | 0.27 | Capacitor_THT:C_Disc_D5.1mm_W3.2mm_P5.00mm | https://www.digikey.pt/en/products/detail/kemet/C320C104K5R5TA/818040 | 3.78 | 0 | 14 | 50 | 0.1162 | 1.6268 | 5.81
Caux1,Caux2,Caux3,Caux4,CFs1,CFs2 | 6 | 1uF - Cer | 0.63 | Capacitor_THT:C_Disc_D5.1mm_W3.2mm_P5.00mm,Capacitor_THT:C_Disc_D7.5mm_W4.4mm_P5.00mm | https://www.digikey.pt/en/products/detail/kemet/C330C105M5U5TA/818166 | 3.78 | 0 | 6 | 10 | 0.391 | 2.346 | 3.91
Cdc1,Cdc2,Cdc4,Cdc5 | 4 | 10uF | 0.09 | Capacitor_THT:CP_Radial_D5.0mm_P2.00mm | https://www.digikey.pt/en/products/detail/w%C3%BCrth-elektronik/860020472003/5727057 | 0.36 | 8 | -4 | 0 | 0 | 0 | 0
Cdc3,Cvcc5,Cvcc6 | 3 | 10uF - Tant | 0.63 | PCM_Capacitor_THT_AKL:CP_Radial_Tantal_D6.0mm_P2.50mm | https://www.digikey.pt/en/products/detail/kyocera-avx/TAP106M035SCS/1471228 | 1.89 | 0 | 3 | 10 | 0.398 | 1.194 | 3.98
Cdc6,Cdc7,Cdc8,Cdc9,Cdc10,Cdc11,Cdc12 | 7 | 1uF | 0.09 | Capacitor_THT:CP_Radial_D5.0mm_P2.00mm | https://www.digikey.pt/en/products/detail/w%C3%BCrth-elektronik/860020672005/5727088 | 0.63 | 6 | 1 | 50 | 0.0762 | 0.0762 | 3.81
Cdc13 | 1 | 0.33uF - Tant | 0.56 | PCM_Capacitor_THT_AKL:CP_Radial_Tantal_D6.0mm_P2.50mm | https://www.digikey.pt/en/products/detail/kyocera-avx/TAP334K035SRW/1471718 | 0.56 | 0 | 1 | 10 | 0.346 | 0.346 | 3.46
Cdc14 | 1 | 0.10uF - Tant | 0.41 | PCM_Capacitor_THT_AKL:CP_Radial_Tantal_D6.0mm_P2.50mm | https://www.digikey.pt/en/products/detail/kyocera-avx/TAP104M050SCS/1471017 | 0.41 | 0 | 1 | 10 | 0 | 0 | 0
CF1,CF2,CF3,CF4,CF5 | 5 | 1nF - Cer | 0.3 | Capacitor_THT:C_Disc_D9.0mm_W5.0mm_P5.00mm | https://www.digikey.pt/en/products/detail/vishay-beyschlag-draloric-bc-components/S102K33Y5PP63K5R/2356789 | 1.5 | 0 | 5 | 10 | 0.178 | 0.89 | 1.78
Cfan1,Cfan2,Cfan3,Cfan4 | 4 | 100uF | 0.11 | Capacitor_THT:CP_Radial_D5.0mm_P2.00mm | https://www.digikey.pt/en/products/detail/w%C3%BCrth-elektronik/860020473008/5727062 | 0.44 | 0 | 4 | 50 | 0.0986 | 0.3944 | 4.93
Cfilt1,Cfilt2,Cfilt3 | 3 | 10uF 310Vac 630Vdc | 5.64 | Custom:C4AF9BW5100T3JK | https://www.digikey.pt/en/products/detail/kemet/C4AF9BW5100T3JK/14312514 | 16.92 | 0 | 3 | 3 | 5.64 | 16.92 | 16.92
Cprot1 | 1 | 10nF - Cer | 0.26 | Capacitor_THT:C_Disc_D6.0mm_W2.5mm_P5.00mm | https://www.digikey.pt/en/products/detail/kemet/C315C103K5R5TA/817924 | 0.26 | 9 | -8 | 0 | 0 | 0 | 0
Cvcc1,Cvcc3,Cvcc4 | 3 | 47uF | 0.09 | Capacitor_THT:CP_Radial_D5.0mm_P2.00mm | https://www.digikey.pt/en/products/detail/w%C3%BCrth-elektronik/860020472006/5727060 | 0.27 | 0 | 3 | 50 | 0.0762 | 0.2286 | 3.81
Cvcc2 | 1 | 470uF | 0.3 | Capacitor_THT:CP_Radial_D5.0mm_P2.00mm | https://www.digikey.pt/en/products/detail/w%C3%BCrth-elektronik/860020474014/5727068 | 0.3 | 0 | 1 | 5 | 0.3 | 0.3 | 1.5
Dadc1,Dadc2,Dadc3,Dadc4,Dadc5,Dadc6 | 6 | 1N5819 | 0.29 | PCM_Diode_THT_AKL:D_DO-15_P10.16mm_Horizontal | https://www.digikey.pt/en/products/detail/diotec-semiconductor/1N5819/13164178 | 1.74 | 0 | 6 | 100 | 0.093 | 0.558 | 9.3
Dhcpl1,Dhcpl2,Dhcpl3,Dhcpl4,Dhcpl5,Dhcpl6,Dhcpl7,Dhcpl8,Dhcpl9,Dhcpl10,Dhcpl11 | 11 | 1.8V | 0.15 | LED_THT:LED_D5.0mm | https://www.digikey.pt/en/products/detail/liteon/LTL2R3KRD-EM/2675133 | 1.65 | 0 | 11 | 300 | 0.0735 | 0.8085 | 22.05
Drel1,Drel2,Drel3,Dwheel1 | 4 | 1N5408 | 0.3 | PCM_Diode_THT_AKL:D_DO-27_P12.70mm_Horizontal,PCM_Diode_THT_AKL:D_DO-27_P5.08mm_Vertical_AnodeUp | https://www.digikey.pt/en/products/detail/diotec-semiconductor/1N5408/13163974 | 1.2 | 0 | 4 | 10 | 0.182 | 0.728 | 1.82
DZprot1 | 1 | 3V3 | 0.22 | Diode_THT:D_DO-41_SOD81_P7.62mm_Horizontal | https://www.digikey.pt/en/products/detail/onsemi/1N4728A/977183 | 0.22 | 0 | 1 | 10 | 0.135 | 0.135 | 1.35
H1,H2,H3,H4,H5,H6,H7,H8,H9,H10,H11,H12,H13,H14,H15 | 15 | MountingHole_M3 | 0 | MountingHole:MountingHole_3.2mm_M3 |  | 0 | 0 | 15 | 0 | 0 | 0 | 0
JCond1,JCond2,Jfilt1,Jfilt2 | 4 | Screw_Terminal_01x03 | 6.36 | Custom:CONN3_2604-3103_WAG | https://www.digikey.pt/en/products/detail/wago-corporation/2604-1101/15522416 | 25.44 | 0 | 4 | 0 | 0 | 0 | 0 | 12 | 3
Jdac1,Jdac2 | 2 | PINHD_1x3_Male | 0 | Connector_PinHeader_2.54mm:PinHeader_1x03_P2.54mm_Vertical | ---------------------------------------------------------------- | 0 | 0 | 2 | 0 | 0 | 0 | 0 | 0
Jdisp1 | 1 | PINHD_1x7_Male | 0 | Connector_PinHeader_2.54mm:PinHeader_1x07_P2.54mm_Vertical | ---------------------------------------------------------------- | 0 | 0 | 1 | 0 | 0 | 0 | 0 | 0
Jenc1 | 1 | PINHD_1x5_Male | 0 | Connector_PinHeader_2.54mm:PinHeader_1x05_P2.54mm_Vertical | ---------------------------------------------------------------- | 0 | 0 | 1 | 0 | 0 | 0 | 0 | 0
JmonoCtrl1 | 1 | Screw_Terminal_01x07 | 8.1382 | Custom:CONN4_2604-3107_WAG | https://www.digikey.pt/en/products/detail/wago-corporation/2604-1101/15522416 | 8.1382 | 0 | 1 | 0 | 0 | 0 | 0 | 7 | 7
Jrel1,Jrel2,JSense1 | 3 | Screw_Terminal_01x04 | 8.48 | Custom:CONN4_2604-3104_WAG | https://www.digikey.pt/en/products/detail/wago-corporation/2604-1101/15522416 | 25.44 | 0 | 3 | 0 | 0 | 0 | 0 | 12 | 4
Jsense2,Jsense3 | 2 | Screw_Terminal_01x06 | 12.72 | Custom:CONN4_2604-3106_WAG | https://www.digikey.pt/en/products/detail/wago-corporation/2604-1101/15522416 | 25.44 | 0 | 2 | 0 | 0 | 0 | 0 | 12 | 6
Jsoft1,Jsoft2,JSource1 | 3 | Screw_Terminal_01x02 | 4.24 | Custom:CONN2_2604-3102_WAG | https://www.digikey.pt/en/products/detail/wago-corporation/2604-1101/15522416 | 12.72 | 0 | 3 | 0 | 0 | 0 | 0 | 6 | 2
JtrifCtrl1 | 1 | Screw_Terminal_01x11 | 23.32 | Custom:CONN4_2604-3111_WAG | https://www.digikey.pt/en/products/detail/wago-corporation/2604-1101/15522416 | 23.32 | 2 | 60 | 65 | 1.1978 | 71.868 | 77.857 | 11 | 11
K1,K2,K3 | 3 | SPDT 16A 12V | 5.8 | Custom:RELAY_G2R-1-E AC12_OMR | https://www.digikey.pt/en/products/detail/omron-electronics-inc-emc-div/G2R-1-E-DC12/153649 | 17.4 | 0 | 3 | 3 | 5.8 | 17.4 | 17.4
Lfilt1,Lfilt2,Lfilt3 | 3 | 330uH 3A | 4.55 | Custom:IND_PE-53117NL_PUL | https://www.digikey.pt/en/products/detail/pulse-electronics/PE-53117NL/2266021 | 13.65 | 0 | 3 | 3 | 4.55 | 13.65 | 13.65
M20mm1,M20mm2,M20mm3,M20mm4 | 4 | 5V 0.23A | 0 | Connector_PinHeader_2.54mm:PinHeader_2x01_P2.54mm_Vertical | ---------------------------------------------------------------- | 0 | 0 | 4 | 0 | 0 | 0 | 0
M120mm1 | 1 | 12V 0.3A | 0 | Connector:FanPinHeader_1x03_P2.54mm_Vertical | ---------------------------------------------------------------- | 0 | 0 | 1 | 0 | 0 | 0 | 0
OCiso1,OCiso2,OCiso3,OCiso4,OCiso5,OCiso6,OCiso7,OCiso8,OCiso9,OCiso10,OCiso11 | 11 | HCPL-3120 | 4.69 | PCM_Package_DIP_AKL:DIP-8_W7.62mm_LongPads | https://www.digikey.pt/en/products/detail/broadcom-limited/HCPL-3120/637386 | 51.59 | 10 | 1 | 5 | 4.69 | 4.69 | 23.45
Qfan1 | 1 | IRLZ44N | 1.96 | PCM_Package_TO_SOT_THT_AKL:TO-220-3_Vertical_GDS | https://www.digikey.pt/en/products/detail/infineon-technologies/IRLZ44NPBF/811808 | 1.96 | 0 | 1 | 2 | 1.96 | 1.96 | 3.92
Qrel1,Qrel2 | 2 | 2N2222A | 0.18 | PCM_Package_TO_SOT_THT_AKL:TO-92_Inline_Wide_EBC | https://www.digikey.pt/en/products/detail/diotec-semiconductor/2N2222A/13164037 | 0.36 | 40 | -38 | 0 | 0 | 0 | 0
Radc1,Radc2,Radc3 | 3 | 33 | 0.09 | Resistor_THT:R_Axial_DIN0309_L9.0mm_D3.2mm_P2.54mm_Vertical | CF12JT33R0 Stackpole Electronics Inc | Through Hole Resistors | DigiKey (https://www.digikey.pt/en/products/detail/stackpole-electronics-inc/CF12JT33R0/1741128) | 0.27 | 0 | 3 | 100 | 0.0202 | 0.0606 | 2.02
Rdiv1,Rgs1,Rgs2,Rgs3,Rgs4,Rgs5,Rgs6,Rgs7,Rgs8,Rgs9,Rgs10,Rgs11,Rprot1,Rtemp1 | 14 | 10k | 0.1 | Resistor_THT:R_Axial_DIN0309_L9.0mm_D3.2mm_P2.54mm_Vertical | https://www.digikey.pt/en/products/detail/stackpole-electronics-inc/CF12JT10K0/1741024 | 1.4 | 40 | -26 | 0 | 0 | 0 | 0
RF1,RF2,RF3,RF4,RF5 | 5 | 100 | 0.09 | Resistor_THT:R_Axial_DIN0309_L9.0mm_D3.2mm_P2.54mm_Vertical | https://www.digikey.pt/en/products/detail/stackpole-electronics-inc/CF14JT100R/1741261 | 0.45 | 0 | 5 | 100 | 0.0149 | 0.0745 | 1.49
Rfan1,Rled1,Rled2,Rled3,Rled4,Rled5,Rled6,Rled7,Rled8,Rled9,Rled10,Rled11 | 12 | 330 | 0.1 | Resistor_THT:R_Axial_DIN0309_L9.0mm_D3.2mm_P2.54mm_Vertical | https://www.digikey.pt/en/products/detail/stackpole-electronics-inc/CFM12JT330R/1741936 | 1.2 | 7 | 5 | 100 | 0.0174 | 0.087 | 1.74
Rfilt1,Rfilt2,Rfilt3 | 3 | 100 OHM 5% 10W | 1.11 | Custom:VM10JB100R | https://www.digikey.pt/en/products/detail/stackpole-electronics-inc/VM10JB100R/6274874 | 3.33 | 0 | 3 | 10 | 0.729 | 2.187 | 7.29
RFs1,RFs2,Rrel1,Rrel2 | 4 | 1k | 0.1 | Resistor_THT:R_Axial_DIN0309_L9.0mm_D3.2mm_P2.54mm_Vertical | https://www.digikey.pt/en/products/detail/stackpole-electronics-inc/CF12JT1K00/1741062 | 0.4 | 80 | -76 | 0 | 0 | 0 | 0
Rg1,Rg2,Rg3,Rg4,Rg5,Rg6,Rg7,Rg8,Rg9,Rg10,Rg11 | 11 | 22 | 0.09 | Resistor_THT:R_Axial_DIN0309_L9.0mm_D3.2mm_P2.54mm_Vertical | https://www.digikey.pt/en/products/detail/stackpole-electronics-inc/CF14JT22R0/1741344 | 0.99 | 0 | 11 | 100 | 0.0149 | 0.1639 | 1.49
Rhcpl1,Rhcpl2,Rhcpl3,Rhcpl4,Rhcpl5,Rhcpl6,Rhcpl7,Rhcpl8,Rhcpl9,Rhcpl10,Rhcpl11 | 11 | 180 | 0.09 | Resistor_THT:R_Axial_DIN0309_L9.0mm_D3.2mm_P2.54mm_Vertical | https://www.digikey.pt/en/products/detail/stackpole-electronics-inc/CF14JT180R/1741307 | 0.99 | 0 | 11 | 100 | 0.0149 | 0.1639 | 1.49
Rsoft1 | 1 | 100 100W | 0.482 | Resistor_THT:R_Axial_Power_L48.0mm_W12.5mm_P10.16mm_Vertical | https://www.digikey.pt/en/products/detail/yageo/RS110/19997 | 0.482 | 0 | 1 | 1 | 0.4823214286 | 0.4823214286 | 81.03 |  | 81.03
RVdiv1 | 1 | 20k | 1.91 | Potentiometer_THT:Potentiometer_Bourns_3296W_Vertical | https://www.digikey.pt/en/products/detail/bourns-inc/PV36W203C01B00/666508 | 1.91 | 1 | 0 | 0 | 0 | 0 | 0
STM1 | 1 | ~ | 5.79 | Library:ST_Morpho_and_Zio_Connectors_144_STLink | https://www.digikey.pt/en/mylists/list/L2R5106XDR | 5.79 | 0 | 1 | 0 | 0 | 0 | 0
TH1 | 1 | NTCALUG02A103G | 5.82 | Custom:CONN2_2604-3102_WAG | https://www.digikey.pt/en/products/detail/vishay-beyschlag-draloric-bc-components/ntcalug02a103g/2640539 | 5.82 | 0 | 1 | 1 | 1.58 | 1.58 | 1.58 | 2
TP-15V1,TP1.65V1,TP3.3V1,TP12V1,TP15V1,TPgnd1,TPgnd2,TPgnd3,TPref1 | 9 | TestPoint | 0 | TestPoint:TestPoint_Keystone_5000-5004_Miniature | ~ | 0 | 0 | 9 | 0 | 0 | 0 | 0
U1 | 1 | TSR_1-2433 | 5.28 | Converter_DCDC:Converter_DCDC_TRACO_TSR-1_THT | https://www.digikey.pt/en/products/detail/traco-power/TSR-1-2433/9383776 | 5.28 | 0 | 1 | 5 | 25.41 | 25.41 | 127.05
UAmp1 | 1 | MCP6002-I-P | 0.38 | PCM_Package_DIP_AKL:DIP-8_W7.62mm_LongPads | https://www.digikey.pt/en/products/detail/microchip-technology/MCP6002-I-P/500875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 | 0.38 | 0 | 1 | 25 | 0.334 | 0.334 | 8.35
Udc1 | 1 | REC30K-2415DZ | 21.52 | Custom:REC30K_RCP | https://www.digikey.pt/en/products/detail/recom-power/REC30K-2415DZ/24366422 | 21.52 | 0 | 1 | 1 | 21.52 | 21.52 | 21.52
Udc2 | 1 | L7812CV | 1 | PCM_Package_TO_SOT_THT_AKL:TO-220-3_Vertical | https://www.digikey.pt/en/products/detail/stmicroelectronics/L7812CV/585973 | 1 | 0 | 1 | 10 | 0.726 | 0.726 | 7.26
Upot1,Upot2,Uref1,Uref2,Uref3,Uref4,Uref5 | 7 | MEV1S1515SC | 6.17 | Library:MEV1S1505SC | https://www.digikey.pt/en/products/detail/murata-power-solutions-inc/MEV1S1515SC/2184911 | 43.19 | 2 | 5 | 10 | 5.844 | 29.22 | 58.44
Usense1,Usense2,Usense3 | 3 | LA100-P | 26.75 | Sensor_Current:LEM_LA25-P | https://www.digikey.pt/en/products/detail/lem-usa-inc/LA-100-P/409824 | 80.25 | 0 | 3 | 3 | 26.75 | 80.25 | 80.25
 |  |  |  |  |  | 416.0202 |  |  |  |  | 298.3787214 | 621.707

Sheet: INV
Reference | Qty | Value | Price | Footprint | Datasheet | Custo | Back |  |  |  |  |  | Buy
CAmp1 | 1 | 0.1uF | 0.27 | Capacitor_THT:C_Disc_D5.1mm_W3.2mm_P5.00mm | https://www.digikey.pt/en/products/detail/kemet/C320C104K5R5TA/818040 | 0.27 |  |  |  | 1 |  |  | 14
Caux1,Caux2,Caux3,Caux4 | 4 | 1uF | 0.63 | Capacitor_THT:C_Disc_D5.1mm_W3.2mm_P5.00mm | https://www.digikey.pt/en/products/detail/kemet/C330C105M5U5TA/818166 | 2.52 |  |  |  | 4
Caux5,Caux6 | 2 | 0.1uF | 0.27 | Capacitor_THT:C_Disc_D5.1mm_W3.2mm_P5.00mm | https://www.digikey.pt/en/products/detail/kemet/C320C104K5R5TA/818040 | 0.54 |  |  |  | 2
Chcpl1,Chcpl2,Chcpl3,Chcpl4,Chcpl5,Chcpl6,Chcpl7,Chcpl8,Chcpl9,Chcpl10,Chcpl11 | 11 | 0.1uF | 0.27 | Capacitor_THT:C_Disc_D5.1mm_W3.2mm_P5.00mm | https://www.digikey.pt/en/products/detail/kemet/C320C104K5R5TA/818040 | 2.97 |  |  |  | 11
Cprot1 | 1 | 10nF | 0.26 | Capacitor_THT:C_Disc_D6.0mm_W2.5mm_P5.00mm | https://www.digikey.pt/en/products/detail/kemet/C315C103K5R5TA/817924 | 0.26 | 9 |  |  | -8
CFs1,CFs2 | 2 | 1uF | 0.63 | Capacitor_THT:C_Disc_D7.5mm_W4.4mm_P5.00mm | https://www.digikey.pt/en/products/detail/kemet/C330C105M5U5TA/818166 | 1.26 |  |  |  | 2
CF1,CF2,CF3,CF4,CF5 | 5 | 1nF | 0.3 | Capacitor_THT:C_Disc_D9.0mm_W5.0mm_P5.00mm | https://www.digikey.pt/en/products/detail/vishay-beyschlag-draloric-bc-components/S102K33Y5PP63K5R/2356789 | 1.5 |  |  |  | 5
Cdc1,Cdc2,Cdc4,Cdc5 | 4 | 10uF | 0.09 | Capacitor_THT:CP_Radial_D5.0mm_P2.00mm | https://www.digikey.pt/en/products/detail/w%C3%BCrth-elektronik/860020472003/5727057 | 0.36 | 8 |  |  | -4
Cdc6,Cdc7,Cdc8,Cdc9,Cdc10,Cdc11,Cdc12 | 7 | 1uF | 0.09 | Capacitor_THT:CP_Radial_D5.0mm_P2.00mm | https://www.digikey.pt/en/products/detail/w%C3%BCrth-elektronik/860020672005/5727088 | 0.63 | 6 |  |  | 1
Cfan1,Cfan2,Cfan3,Cfan4 | 4 | 100uF | 0.11 | Capacitor_THT:CP_Radial_D5.0mm_P2.00mm | https://www.digikey.pt/en/products/detail/w%C3%BCrth-elektronik/860020473008/5727062 | 0.44 |  |  |  | 4
Cvcc1,Cvcc3,Cvcc4 | 3 | 47uF | 0.09 | Capacitor_THT:CP_Radial_D5.0mm_P2.00mm | https://www.digikey.pt/en/products/detail/w%C3%BCrth-elektronik/860020472006/5727060 | 0.27 |  |  |  | 3
Cvcc2 | 1 | 470uF | 0.3 | Capacitor_THT:CP_Radial_D5.0mm_P2.00mm | https://www.digikey.pt/en/products/detail/w%C3%BCrth-elektronik/860020474014/5727068 | 0.3 |  |  |  | 1
M120mm1 | 1 | 12V 0.3A | 0 | Connector:FanPinHeader_1x03_P2.54mm_Vertical | ---------------------------------------------------------------- | 0 | 9 |  |  | -8
Jdac1,Jdac2 | 2 | PINHD_1x3_Male | 0 | Connector_PinHeader_2.54mm:PinHeader_1x03_P2.54mm_Vertical | ---------------------------------------------------------------- | 0 | 10 |  |  | -8
Jenc1 | 1 | PINHD_1x5_Male | 0 | Connector_PinHeader_2.54mm:PinHeader_1x05_P2.54mm_Vertical | ---------------------------------------------------------------- | 0 |  |  |  | -8
Jdisp1 | 1 | PINHD_1x7_Male | 0 | Connector_PinHeader_2.54mm:PinHeader_1x07_P2.54mm_Vertical | ---------------------------------------------------------------- | 0 |  |  |  | -8
M20mm1,M20mm2,M20mm3,M20mm4 | 4 | 5V 0.23A | 0 | Connector_PinHeader_2.54mm:PinHeader_2x01_P2.54mm_Vertical | ---------------------------------------------------------------- | 0 |  |  |  | -8
U1 | 1 | TSR_1-2433 | 5.28 | Converter_DCDC:Converter_DCDC_TRACO_TSR-1_THT | https://www.digikey.pt/en/products/detail/traco-power/TSR-1-2433/9383776 | 5.28 |  |  |  | 1
Cfilt1,Cfilt2,Cfilt3 | 3 | 10uF 310Vac 630Vdc | 5.64 | Custom:C4AF9BW5100T3JK | https://www.digikey.pt/en/products/detail/kemet/C4AF9BW5100T3JK/14312514 | 16.92 |  |  |  | 3
JBrk1 | 1 | Screw_Terminal_01x02 | 4.24 | Custom:CONN2_2604-3102_WAG | https://www.digikey.pt/en/products/detail/wago-corporation/2604-1101/15522416 | 4.24 | 2 |  | 2 | 0
Jsoft1,Jsoft2 | 2 | Screw_Terminal_01x02 | 4.24 | Custom:CONN2_2604-3102_WAG | https://www.digikey.pt/en/products/detail/wago-corporation/2604-1101/15522416 | 8.48 |  |  | 2 | 4
JSource1 | 1 | Screw_Terminal_01x02 | 4.24 | Custom:CONN2_2604-3102_WAG | https://www.digikey.pt/en/products/detail/wago-corporation/2604-1101/15522416 | 4.24 |  |  | 2 | 2
TH1 | 1 | NTCALUG02A103G | 5.82 | Custom:CONN2_2604-3102_WAG | https://www.digikey.pt/en/products/detail/vishay-beyschlag-draloric-bc-components/ntcalug02a103g/2640539 | 5.82 |  | 0 | 2 | 2 | temp
JCond1 | 1 | Screw_Terminal_01x03 | 6.36 | Custom:CONN3_2604-3103_WAG | https://www.digikey.pt/en/products/detail/wago-corporation/2604-1101/15522416 | 6.36 |  |  | 3 | 3
Jfilt1,Jfilt2 | 2 | Screw_Terminal_01x03 | 6.36 | Custom:CONN3_2604-3103_WAG | https://www.digikey.pt/en/products/detail/wago-corporation/2604-1101/15522416 | 12.72 |  |  | 3 | 6
Jrel1,Jrel2 | 2 | Screw_Terminal_01x04 | 8.48 | Custom:CONN4_2604-3104_WAG | https://www.digikey.pt/en/products/detail/wago-corporation/2604-1101/15522416 | 16.96 |  |  | 4 | 8
JSense1 | 1 | Screw_Terminal_01x04 | 8.48 | Custom:CONN4_2604-3104_WAG | https://www.digikey.pt/en/products/detail/wago-corporation/2604-1101/15522416 | 8.48 |  |  | 4 | 4
Jsense2,Jsense3 | 2 | Screw_Terminal_01x06 | 12.72 | Custom:CONN4_2604-3106_WAG | https://www.digikey.pt/en/products/detail/wago-corporation/2604-1101/15522416 | 25.44 |  |  | 6 | 12
JmonoCtrl1 | 1 | Screw_Terminal_01x07 | 8.1382 | Custom:CONN4_2604-3107_WAG | https://www.digikey.pt/en/products/detail/wago-corporation/2604-1101/15522416 | 8.1382 |  |  | 7 | 7
JtrifCtrl1 | 1 | Screw_Terminal_01x11 | 23.32 | Custom:CONN4_2604-3111_WAG | https://www.digikey.pt/en/products/detail/wago-corporation/2604-1101/15522416 | 23.32 |  |  | 11 | 11 |  | 59
Lfilt1,Lfilt2,Lfilt3 | 3 | 330uH 3A | 4.55 | Custom:IND_PE-53117NL_PUL | https://www.digikey.pt/en/products/detail/pulse-electronics/PE-53117NL/2266021 | 13.65 |  |  |  | 3
Udc2 | 1 | REC30K-2415DZ | 21.52 | Custom:REC30K_RCP | https://www.digikey.pt/en/products/detail/recom-power/REC30K-2415DZ/24366422 | 21.52 |  |  |  | 1
K1,K2,K3 | 3 | SPDT 16A 12V | 5.8 | Custom:RELAY_G2R-1-E AC12_OMR | https://www.digikey.pt/en/products/detail/omron-electronics-inc-emc-div/G2R-1-E-DC12/153649 | 17.4 |  |  |  | 3
Rfilt1,Rfilt2,Rfilt3 | 3 | 100 OHM 5% 10W | 1.11 | Custom:VM10JB100R | https://www.digikey.pt/en/products/detail/stackpole-electronics-inc/VM10JB100R/6274874 | 3.33 |  |  |  | 3
DZprot1 | 1 | 3V3 | 0.22 | Diode_THT:D_DO-41_SOD81_P7.62mm_Horizontal | https://www.digikey.pt/en/products/detail/onsemi/1N4728A/977183 | 0.22 |  |  |  | 1
Dhcpl1,Dhcpl2,Dhcpl3,Dhcpl4,Dhcpl5,Dhcpl6,Dhcpl7,Dhcpl8,Dhcpl9,Dhcpl10,Dhcpl11 | 11 | 1.8V | 0.15 | LED_THT:LED_D5.0mm | https://www.digikey.pt/en/products/detail/liteon/LTL2R3KRD-EM/2675133 | 1.65 |  |  |  | 11
Upot1,Upot2 | 2 | MEV1S1515SC | 6.17 | Library:MEV1S1505SC | https://www.digikey.pt/en/products/detail/murata-power-solutions-inc/MEV1S1515SC/2184911 | 12.34 | 2 |  |  | 0
Uref1,Uref2,Uref3,Uref4,Uref5 | 5 | MEV1S1515SC | 6.17 | Library:MEV1S1505SC | https://www.digikey.pt/en/products/detail/murata-power-solutions-inc/MEV1S1515SC/2184911 | 30.85 | 0 |  |  | 5
STM1 | 1 | ~ | 5.79 | Library:ST_Morpho_and_Zio_Connectors_144_STLink | https://www.digikey.pt/en/mylists/list/L2R5106XDR | 5.79 |  |  |  | 1
Cdc3 | 1 | 10uF - Tant | 0.63 | PCM_Capacitor_THT_AKL:CP_Radial_Tantal_D6.0mm_P2.50mm | https://www.digikey.pt/en/products/detail/kyocera-avx/TAP106M035SCS/1471228 | 0.63 |  |  |  | 1
Cdc13 | 1 | 0.33uF - Tant | 0.56 | PCM_Capacitor_THT_AKL:CP_Radial_Tantal_D6.0mm_P2.50mm | https://www.digikey.pt/en/products/detail/kyocera-avx/TAP334K035SRW/1471718 | 0.56 |  |  |  | 1
Cdc14 | 1 | 0.10uF - Tant | 0.41 | PCM_Capacitor_THT_AKL:CP_Radial_Tantal_D6.0mm_P2.50mm | https://www.digikey.pt/en/products/detail/kyocera-avx/TAP104M050SCS/1471017 | 0.41 |  |  |  | 1
Cvcc5,Cvcc6 | 2 | 10uF - Tant | 0.63 | PCM_Capacitor_THT_AKL:CP_Radial_Tantal_D6.0mm_P2.50mm | https://www.digikey.pt/en/products/detail/kyocera-avx/TAP106M035SCS/1471228 | 1.26 |  |  |  | 2
Dadc1,Dadc2,Dadc3,Dadc4,Dadc5,Dadc6 | 6 | 1N5819 | 0.29 | PCM_Diode_THT_AKL:D_DO-15_P10.16mm_Horizontal | https://www.digikey.pt/en/products/detail/diotec-semiconductor/1N5819/13164178 | 1.74 |  |  |  | 6
Drel1,Drel2,Drel3 | 3 | 1N5408 | 0.3 | PCM_Diode_THT_AKL:D_DO-27_P5.08mm_Vertical_AnodeUp | https://www.digikey.pt/en/products/detail/diotec-semiconductor/1N5408/13163974 | 0.9 |  |  |  | 3
Dwheel1 | 1 | 1N5408 | 0.3 | PCM_Diode_THT_AKL:D_DO-27_P12.70mm_Horizontal | https://www.digikey.pt/en/products/detail/diotec-semiconductor/1N5408/13163974 | 0.3 |  |  |  | 1
OCiso1,OCiso2,OCiso3,OCiso4,OCiso5,OCiso6,OCiso7,OCiso8,OCiso9,OCiso10,OCiso11 | 11 | HCPL-3120 | 4.69 | PCM_Package_DIP_AKL:DIP-8_W7.62mm_LongPads | https://www.digikey.pt/en/products/detail/broadcom-limited/HCPL-3120/637386 | 51.59 | 4 | 7 sockets | 7 16dip | 7 |  |  | 5
UAmp1 | 1 | MCP6002-I-P | 0.38 | PCM_Package_DIP_AKL:DIP-8_W7.62mm_LongPads | https://www.digikey.pt/en/products/detail/microchip-technology/MCP6002-I-P/500875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 | 0.38 |  | lm318n |  | 1
Qrel1,Qrel2 | 2 | 2N2222A | 0.18 | PCM_Package_TO_SOT_THT_AKL:TO-92_Inline_Wide_EBC | https://www.digikey.pt/en/products/detail/diotec-semiconductor/2N2222A/13164037 | 0.36 | 40 |  |  | -38
Udc3 | 1 | L7812CV | 1 | PCM_Package_TO_SOT_THT_AKL:TO-220-3_Vertical | https://www.digikey.pt/en/products/detail/stmicroelectronics/L7812CV/585973 | 1 |  |  |  | 1
Qfan1 | 1 | IRLZ44N | 1.96 | PCM_Package_TO_SOT_THT_AKL:TO-220-3_Vertical_GDS | https://www.digikey.pt/en/products/detail/infineon-technologies/IRLZ44NPBF/811808 | 1.96 |  |  |  | 1
RVdiv1 | 1 | 20k | 1.91 | Potentiometer_THT:Potentiometer_Bourns_3296W_Vertical | https://www.digikey.pt/en/products/detail/bourns-inc/PV36W203C01B00/666508 | 1.91 | 1 |  |  | 0
Radc1,Radc2,Radc3 | 3 | 200 | 0.09 | Resistor_THT:R_Axial_DIN0309_L9.0mm_D3.2mm_P2.54mm_Vertical | https://www.digikey.pt/en/products/detail/stackpole-electronics-inc/CF14JT200R/1741336 | 0.27 |  |  |  | 3
Rdiv1 | 1 | 10k | 0.1 | Resistor_THT:R_Axial_DIN0309_L9.0mm_D3.2mm_P2.54mm_Vertical | https://www.digikey.pt/en/products/detail/stackpole-electronics-inc/CF12JT10K0/1741024 | 0.1 | 40 |  |  | -39
RF1,RF2,RF3,RF4,RF5 | 5 | 100 | 0.09 | Resistor_THT:R_Axial_DIN0309_L9.0mm_D3.2mm_P2.54mm_Vertical | https://www.digikey.pt/en/products/detail/stackpole-electronics-inc/CF14JT100R/1741261 | 0.45 |  |  |  | 5
Rfan1 | 1 | 330 | 0.1 | Resistor_THT:R_Axial_DIN0309_L9.0mm_D3.2mm_P2.54mm_Vertical | https://www.digikey.pt/en/products/detail/stackpole-electronics-inc/CFM12JT330R/1741936 | 0.1 |  |  |  | 1
RFs1,RFs2 | 2 | 1k | 0.1 | Resistor_THT:R_Axial_DIN0309_L9.0mm_D3.2mm_P2.54mm_Vertical | https://www.digikey.pt/en/products/detail/stackpole-electronics-inc/CF12JT1K00/1741062 | 0.2 |  |  |  | 2
Rg1,Rg2,Rg3,Rg4,Rg5,Rg6,Rg7,Rg8,Rg9,Rg10,Rg11 | 11 | 22 | 0.09 | Resistor_THT:R_Axial_DIN0309_L9.0mm_D3.2mm_P2.54mm_Vertical | https://www.digikey.pt/en/products/detail/stackpole-electronics-inc/CF14JT22R0/1741344 | 0.99 |  |  |  | 11
Rgs1,Rgs2,Rgs3,Rgs4,Rgs5,Rgs6,Rgs7,Rgs8,Rgs9,Rgs10,Rgs11 | 11 | 10k | 0.1 | Resistor_THT:R_Axial_DIN0309_L9.0mm_D3.2mm_P2.54mm_Vertical | https://www.digikey.pt/en/products/detail/stackpole-electronics-inc/CF12JT10K0/1741024 | 1.1 | 40 |  |  | -29
Rhcpl1,Rhcpl2,Rhcpl3,Rhcpl4,Rhcpl5,Rhcpl6,Rhcpl7,Rhcpl8,Rhcpl9,Rhcpl10,Rhcpl11 | 11 | 180 | 0.09 | Resistor_THT:R_Axial_DIN0309_L9.0mm_D3.2mm_P2.54mm_Vertical | https://www.digikey.pt/en/products/detail/stackpole-electronics-inc/CF14JT180R/1741307 | 0.99 |  |  |  | 11
Rled1,Rled2,Rled3,Rled4,Rled5,Rled6,Rled7,Rled8,Rled9,Rled10,Rled11 | 11 | 330 | 0.1 | Resistor_THT:R_Axial_DIN0309_L9.0mm_D3.2mm_P2.54mm_Vertical | https://www.digikey.pt/en/products/detail/stackpole-electronics-inc/CFM12JT330R/1741936 | 1.1 | 7 |  |  | 4
Rprot1 | 1 | 10k | 0.1 | Resistor_THT:R_Axial_DIN0309_L9.0mm_D3.2mm_P2.54mm_Vertical | https://www.digikey.pt/en/products/detail/stackpole-electronics-inc/CF12JT10K0/1741024 | 0.1 | 40 |  |  | -39
Rrel1,Rrel2 | 2 | 1k | 0.1 | Resistor_THT:R_Axial_DIN0309_L9.0mm_D3.2mm_P2.54mm_Vertical | https://www.digikey.pt/en/products/detail/stackpole-electronics-inc/CF12JT1K00/1741062 | 0.2 | 80 |  |  | -78
Rtemp1 | 1 | 10k | 0.1 | Resistor_THT:R_Axial_DIN0309_L9.0mm_D3.2mm_P2.54mm_Vertical | https://www.digikey.pt/en/products/detail/stackpole-electronics-inc/CF12JT10K0/1741024 | 0.1 | 40 |  |  | -39
Rsoft1 | 1 | 100 100W | 0.482 | Resistor_THT:R_Axial_Power_L48.0mm_W12.5mm_P10.16mm_Vertical | https://www.digikey.pt/en/products/detail/yageo/RS110/19997 | 0.482 |  |  |  | 1
Usense1,Usense2,Usense3 | 3 | LA100-P | 26.75 | Sensor_Current:LEM_LA25-P | https://www.digikey.pt/en/products/detail/lem-usa-inc/LA-100-P/409824 | 80.25 |  |  |  | 3
 |  |  |  |  |  | 413.9002
 |  |  |  |  | wire < 2.5mm2
 |  |  |  |  | testpoints

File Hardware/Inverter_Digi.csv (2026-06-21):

Reference | Qty | Value | Price | Footprint | Price_conect | DNP | Exclude from BOM | Exclude from Board | Datasheet
C+1,C+2,C+3,C+4,C+5,C+6,C+8,C+11,C+14,C+15,C+16,C+17,C-1,C-2,C-3,C-4,C-5,C-6,C-7,C-8,C-9,Cfive1,Cfive2,Cfive3,Cout1,Cout2,Cout3,Cslow1,Cslow2,Cslow3,CT1,CT2,CT3,Cten1,Cten2,Cten3 | 36 | 100n | 0.10140 | Capacitor_THT:C_Disc_D5.1mm_W3.2mm_P5.00mm
C+7,C+9,C+10,C+12,C+13,C+18 | 6 | 0.1u | 0.10140 | Capacitor_THT:C_Disc_D5.1mm_W3.2mm_P5.00mm
Cbank1 | 1 | 1000u 450V | 16.11 | Capacitor_THT:CP_Radial_D40.0mm_P10.00mm_SnapIn
CbankPWM1 | 1 | 1.5u 1.3kVDC | 19.12 | Capacitor_THT:C_Rect_L31.5mm_W13.0mm_P27.50mm_MKS4
Cbe1,Cbe2,Cbe3,Ccb1,Ccb2,Ccb3 | 6 | 0.47u | 0.09 | Capacitor_THT:CP_Radial_D5.0mm_P2.00mm
Cdc1,Cdc2 | 2 | 10u | 0.08 | Capacitor_THT:CP_Radial_D5.0mm_P2.00mm
Cdc3,Cdc4,Cdc5,Cdc6 | 4 | 1u | 0.08 | Capacitor_THT:CP_Radial_D5.0mm_P2.00mm
Cprot1,Cprot2,Cprot3,Cprot4,Cprot5,Cprot6,Cprot7,Cprot8,Cprot9,Cprot10,Cprot11 | 11 | 10n | 0.127 | Capacitor_THT:C_Disc_D6.0mm_W2.5mm_P5.00mm
CRep1,CRep2,CRep3,CRep4,CRep5,CRep6 | 6 | 4.7u | 0.08 | Capacitor_THT:CP_Radial_D5.0mm_P2.50mm
DAISY_CHAIN1,DC_SOURCE1,TRIF_SOURCE1 | 3 | Conn_01x02_Socket | 2.3252 | Custom:CONN2_2604-3102_WAG |  |  |  |  | ~
Dhcpl1,Dhcpl2,Dhcpl3,Dhcpl4,Dhcpl5,Dhcpl6 | 6 | 1.8V | 0 | LED_THT:LED_D5.0mm
Dwheel1 | 1 | D | 0 | Diode_THT:D_DO-27_P15.24mm_Horizontal |  |  |  |  | ~
DZprot1,DZprot2,DZprot3,DZprot4,DZprot5,DZprot6,DZprot7,DZprot8,DZprot9,DZprot10,DZprot11 | 11 | 15 | 0.0424 | Diode_THT:D_DO-34_SOD68_P10.16mm_Horizontal |  |  |  |  | ~
FLin1 | 1 | 15A 1mH | 9.85 | Custom:CHOKE_031501_WRE |  |  |  |  | https://www.schaffner.com/products/download/product/datasheet/rn-series-common-mode-chokes-new/
FLout1 | 1 | 18A 1.5mH | 10.63 | Custom:SCF31B-180-S1R7A013J |  |  |  |  | ~
Fprot1 | 1 | Fuse | 2.94 | Custom:CONN2_2604-3102_WAG | 2.3252 |  |  |  | ~
H2,H3,H4,H6,H7,H8,H9,H10,H11,H12,H13,H14,H15,H16,H17,H18,H19,H20 | 18 | MountingHole_M3 | 0 | MountingHole:MountingHole_3.2mm_M3
HS1,HS2,HS3,HS4,HS5,HS6,HS7,HS8,HS9,HS10 | 10 | Heatsink | 1.639 | Custom:Heatsink_Fischer_SK129-STS_42x25mm_2xDrill2.5mm |  |  |  |  | ~
JinAC1,JinDC1,JoutDC1 | 3 | Screw_Terminal_01x02 | 2.3252 | Custom:CONN2_2604-3102_WAG |  |  |  |  | ~
JmonoCtrl1 | 1 | Screw_Terminal_01x07 | 8.1382 | Custom:CONN4_2604-3107_WAG |  |  |  |  | ~
JoutAC1 | 1 | Screw_Terminal_01x03 | 3.4878 | Custom:CONN3_2604-3103_WAG |  |  |  |  | ~
JtrifCtrl1,JtrifSig1 | 2 | Screw_Terminal_01x11 | 12.7886 | Custom:CONN4_2604-3111_WAG |  |  |  |  | ~
M20mm1,M20mm2,M20mm3,M20mm4 | 4 | 5V 0.23A | 0 | Connector_PinHeader_2.54mm:PinHeader_2x01_P2.54mm_Vertical |  |  |  |  | ~
M120mm1 | 1 | 12V 0.3A | 0 | Connector:FanPinHeader_1x03_P2.54mm_Vertical |  |  |  |  | http://www.hardwarecanucks.com/forum/attachments/new-builds/16287d1330775095-help-chassis-power-fan-connectors-motherboard-asus_p8z68.jpg
OCiso1,OCiso2,OCiso3,OCiso4,OCiso5,OCiso6 | 6 | HCPL-3120 | 4.81 | PCM_Package_DIP_AKL:DIP-8_W7.62mm_LongPads |  |  |  |  | https://www.tme.eu/Document/bcfa583165682b5d610f22669b968a5b/HCNW3120-000E.pdf
OSCIL1,OSCIL2,OSCIL3,OSCIL4,OSCIL5,OSCIL6,TRIF_CMD1,TRIF_CMD2,TRIF_CMD3 | 9 | Magnetic_3 | 5.95 | Custom:3pin_Magnet_5360 |  |  |  |  | ~
PSsource1 | 1 | VTX-214-015-115 | 8.6 | Custom:IRM-15_MWU |  |  |  |  | http://www.vigortronix.com/15WattSMPSPCBModuleAC-DC
Qbreak1,Qbridge1,Qbridge2,Qbridge3,Qbridge4,Qbridge5,Qbridge6,Qbridge7,Qbridge8,Qbridge9,Qbridge10 | 11 | 600V40A | 1.3386 | Custom:TO-220_High |  |  |  |  | https://www.tme.eu/Document/3d0f1152e66224fa282804db9c407ed3/STGW60V60DF.pdf
Qnor1,Qnor2,Qnor3,Qosc1,Qosc2,Qosc3,Qosc4,Qosc5,Qosc6 | 9 | 2N2222A | 0.0635 | PCM_Package_TO_SOT_THT_AKL:TO-92_Inline_Wide_EBC |  |  |  |  | https://www.st.com/resource/en/datasheet/cd00003223.pdf
RAmp1,RAmp2,RAmp3,RAmp4,RAmp5,RAmp6,Rb4,Rb5,Rb6,Rb7,Rb8,Rb9,Rc4,Rc5,Rc6,Rdiv1,Rdiv2,Rdiv3,Rdiv4,Rdiv5,Rdiv6,Rdiv7,Rdiv8,Rdiv9,Rgs1,Rgs2,Rgs3,Rgs4,Rgs5,Rgs6,RPup1,RRep1,RRep2,RRep3,RRep4,RRep5,RRep6 | 37 | 10k | 0.0165 | Resistor_THT:R_Axial_DIN0309_L9.0mm_D3.2mm_P12.70mm_Horizontal,Resistor_THT:R_Axial_DIN0309_L9.0mm_D3.2mm_P2.54mm_Vertical
Rb1,Rb2,Rb3 | 3 | 1M | 0.02400 | Resistor_THT:R_Axial_DIN0309_L9.0mm_D3.2mm_P12.70mm_Horizontal
Rbe1,Rbe2,Rbe3,Rc1,Rc2,Rc3 | 6 | 100k | 0.024 | Resistor_THT:R_Axial_DIN0309_L9.0mm_D3.2mm_P12.70mm_Horizontal
Rbreak1,Rsafety1 | 2 | 33k | 0.72 | Resistor_THT:R_Axial_Power_L48.0mm_W12.5mm_P10.16mm_Vertical |  |  |  |  | https://www.yageogroup.com/content/datasheet/asset/file/YAGEO-SQP_NSP_DATASHEET
Rcomp1,Rcomp2,Rcomp3 | 3 | 330 | 0.022 | Resistor_THT:R_Axial_DIN0309_L9.0mm_D3.2mm_P12.70mm_Horizontal
REq1,REq2,REq3,REq4,REq5,REq6 | 6 | 47 | 0.021 | Resistor_THT:R_Axial_DIN0309_L9.0mm_D3.2mm_P2.54mm_Vertical
Rg1,Rg2,Rg3,Rg4,Rg5,Rg6 | 6 | 22 | 0.024 | Resistor_THT:R_Axial_DIN0309_L9.0mm_D3.2mm_P2.54mm_Vertical
Rled1,Rled2,Rled3,Rled4,Rled5,Rled6 | 6 | 1.2k | 0.021 | Resistor_THT:R_Axial_DIN0309_L9.0mm_D3.2mm_P12.70mm_Horizontal
Rpup2,Rpup3,Rpup4,Rstart1 | 4 | 2.2k | 0.024 | Resistor_THT:R_Axial_DIN0309_L9.0mm_D3.2mm_P12.70mm_Horizontal,Resistor_THT:R_Axial_DIN0309_L9.0mm_D3.2mm_P2.54mm_Vertical
RT1,RT2,RT3 | 3 | 1k | 0.0165 | Resistor_THT:R_Axial_DIN0309_L9.0mm_D3.2mm_P2.54mm_Vertical
RVAmp1,RVAmp2,RVAmp3,RVAmp4,RVAmp5,RVAmp6 | 6 | 20K | 1.095 | Potentiometer_THT:Potentiometer_Bourns_3296W_Vertical
RVRep1,RVRep2 | 2 | 50K | 1.3 | Potentiometer_THT:Potentiometer_Bourns_3296W_Vertical
SWfan1 | 1 | SW_SPST | 0 | Connector_JST:JST_XH_B2B-XH-A_1x02_P2.50mm_Vertical |  |  |  |  | ~
SWphase1 | 1 | SW_Push_DPDT | 3.28 | Custom:CONN9_2601-3109_WAG |  |  |  |  | ~https://app.adam-tech.com/products/download/data_sheet/203453/sw-t2-6x-b-a2-m3-data-sheet.pdf
TRiso1 | 1 | 1:1 | -- | Custom:CONN4_2604-3104_WAG | 4.6504
U+-1 | 1 | TMR_1-0522SM | 20.89 | Custom:REC30K_RCP |  |  |  |  | http://assets.tracopower.com/TMR1SM/documents/tmr1sm-datasheet.pdf
Udead1,Udead2,Udead3 | 3 | LM393 | 0.4245 | Package_DIP:DIP-8_W7.62mm_LongPads |  |  |  |  | http://www.ti.com/lit/ds/symlink/lm393.pdf
Upot1,Uref1,Uref2,Uref3 | 4 | TMR_1-1215 | 9.668 | Custom:DC_MEV3_7P65X19P65_MUR |  |  |  |  | https://power.murata.com/pub/data/power/ncl/kdc_mee1.pdf
Upwm1,Upwm2,Upwm3 | 3 | TL494 | 0.51 | PCM_Package_DIP_AKL:DIP-16_W7.62mm |  |  |  |  | http://www.ti.com/lit/ds/symlink/tl494.pdf
URep1,URep2,URep3,URep4,URep5,URep6 | 6 | LM318N | 1.203 | PCM_Package_DIP_AKL:DIP-8_W7.62mm_LongPads |  |  |  |  | https://www.ti.com/lit/ds/symlink/lm318-n.pdf
Wsense1 | 1 | ~ | 12.44 | Custom:CONN4_2604-3104_WAG | 4.6504

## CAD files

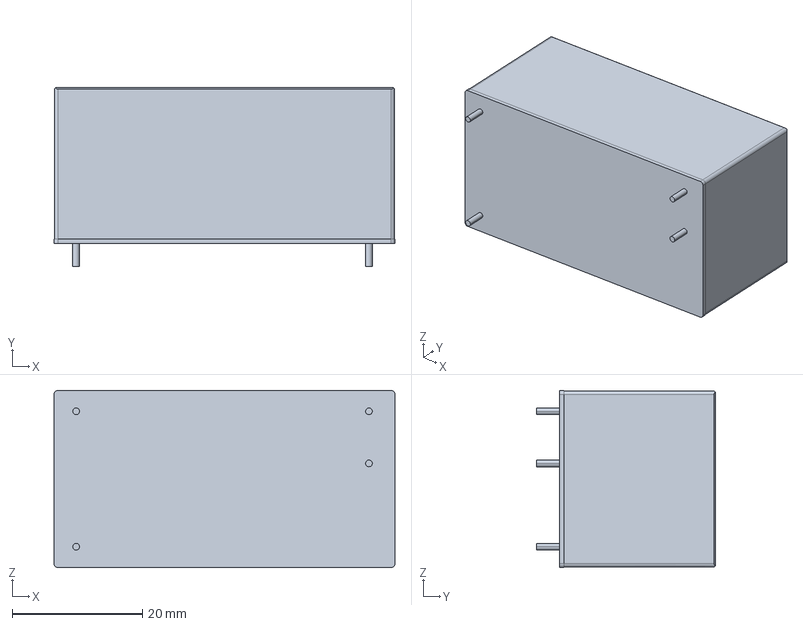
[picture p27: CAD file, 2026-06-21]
Hardware/176289641-3-power_supply_irm-15-15/power_supply_irm-15-15.stp
52.4 x 27.5 x 27.2 mm

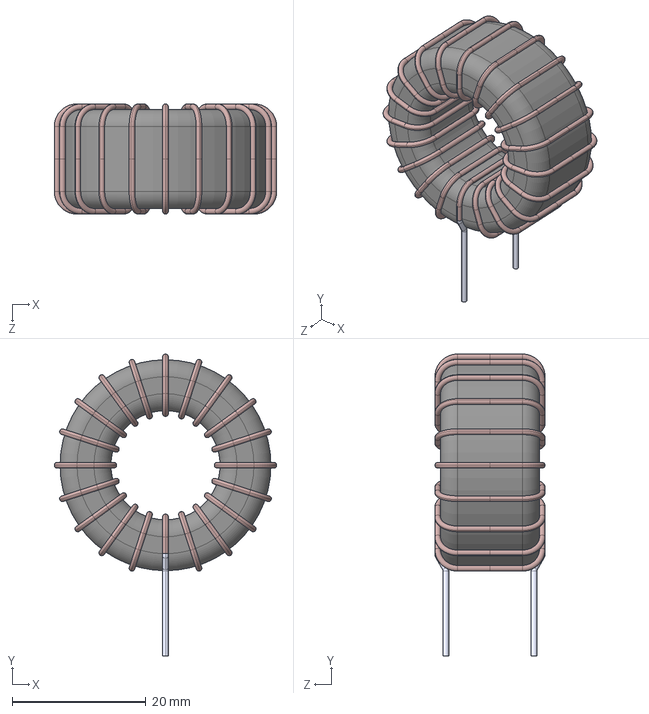
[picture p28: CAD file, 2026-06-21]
Hardware/2300LL_102_V_RC (2)/2300LL-102-V-RC.step
33.3 x 45.2 x 16.5 mm

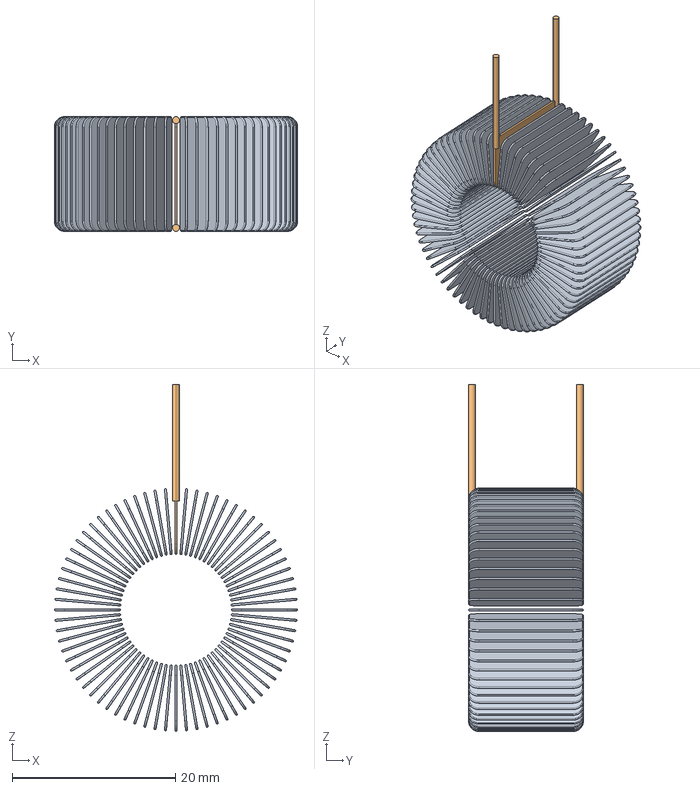
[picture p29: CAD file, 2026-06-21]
Hardware/BackUp/27_12_25/2300ll-102-v-rc.stp
29.8 x 14.1 x 42.5 mm

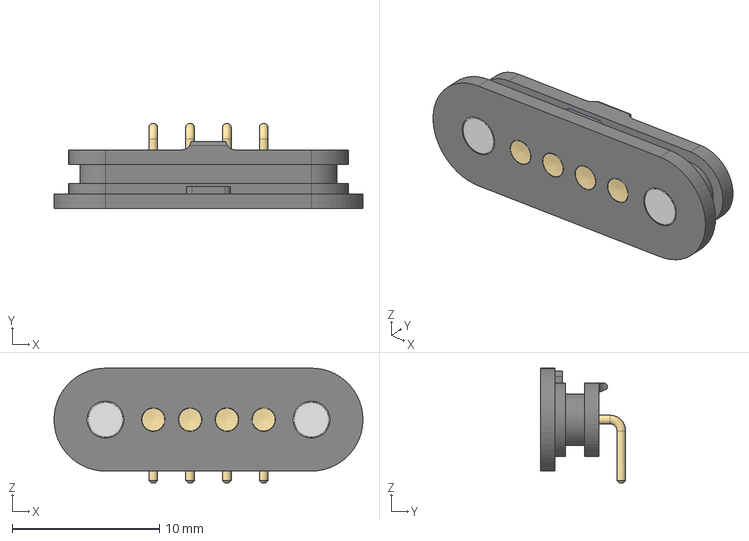
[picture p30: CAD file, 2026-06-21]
Hardware/BackUp/27_12_25/LIB_5358/5358/3D/5358.stp
21.0 x 5.80 x 7.80 mm

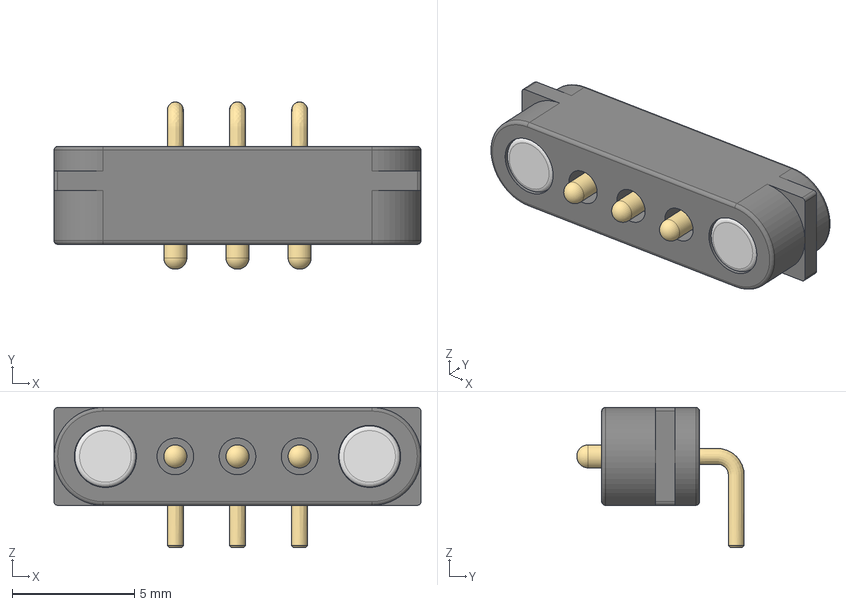
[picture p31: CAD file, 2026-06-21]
Hardware/BackUp/27_12_25/LIB_5360/5360/3D/5360.stp
15.0 x 6.84 x 5.73 mm

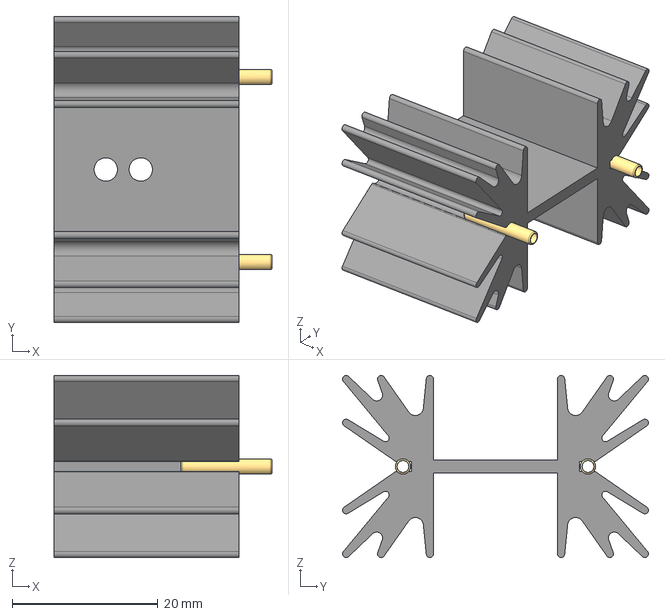
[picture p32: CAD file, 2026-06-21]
Hardware/BackUp/27_12_25/LIB_SK_129_25,4_STS/SK_129_25,4_STS/3D/SK_129_25,4_STS.stp
29.9 x 42.0 x 25.0 mm
SK_129_STS
STS x 2

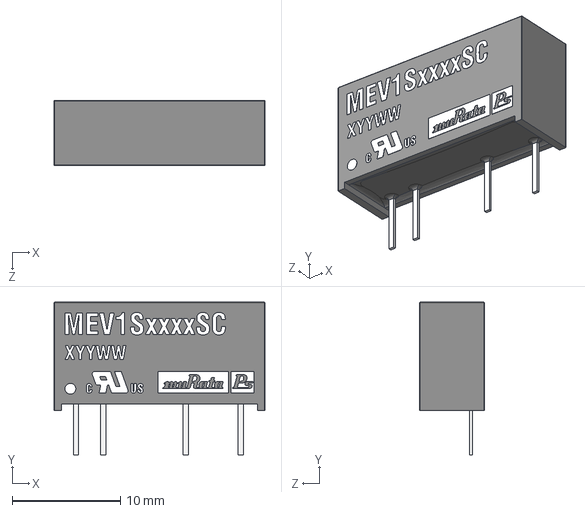
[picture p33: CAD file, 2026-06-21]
Hardware/BackUp/27_12_25/mps_dcdc_mev1s_5_12_15_24vin_sc_a_step (1)/mps_dcdc_mev1s_5&12&15&24vin_sc_a.step
19.5 x 14.1 x 6.02 mm

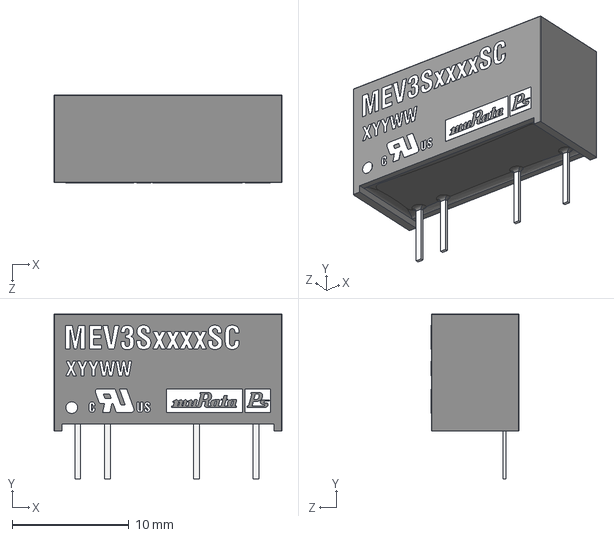
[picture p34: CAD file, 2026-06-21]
Hardware/mps_dcdc_mev3s_sc_a_step/mps_dcdc_mev3s_sc_a.STEP
19.5 x 14.1 x 7.52 mm

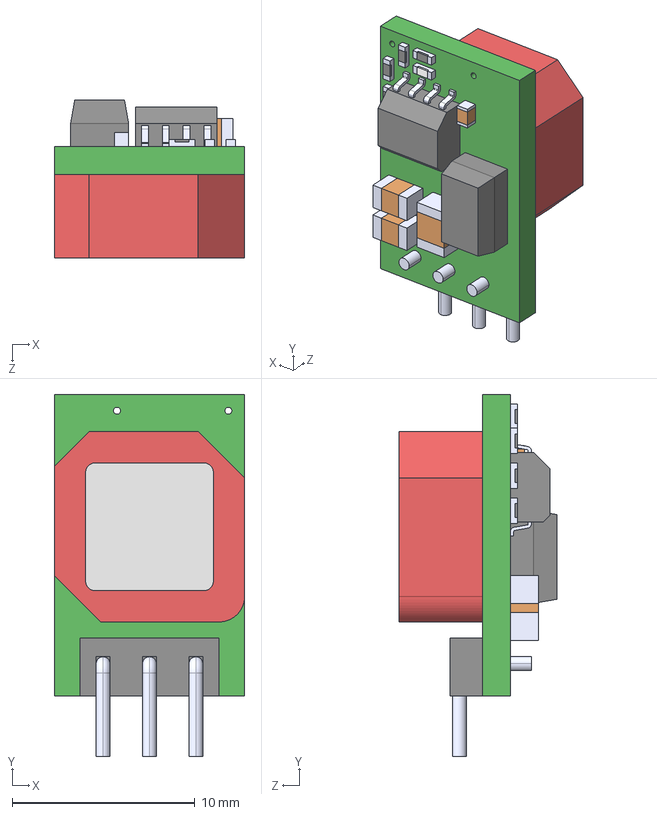
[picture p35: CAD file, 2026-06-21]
Hardware/OKI-78SR-5_1.5-W36-C/OKI-78SR-5_1.5-W36-C.step
10.4 x 19.8 x 8.64 mm

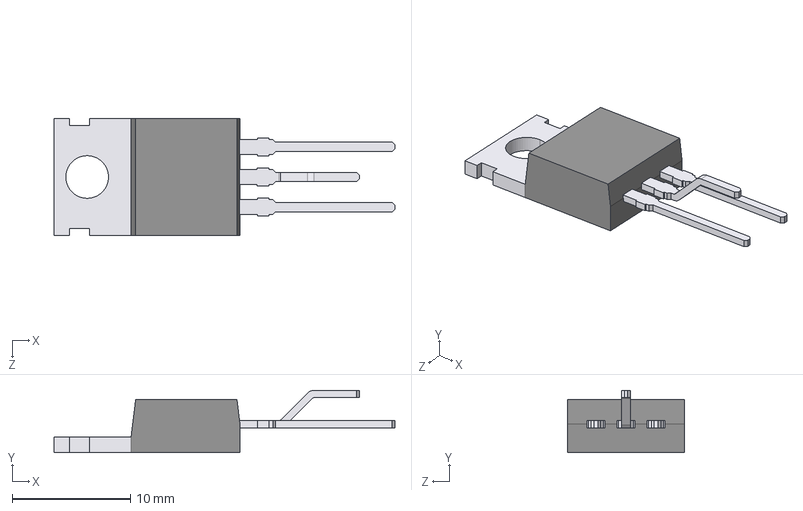
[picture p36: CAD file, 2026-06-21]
Hardware/to-220-6.snapshot.1/TO-220-Vert.STEP
28.8 x 5.24 x 9.90 mm

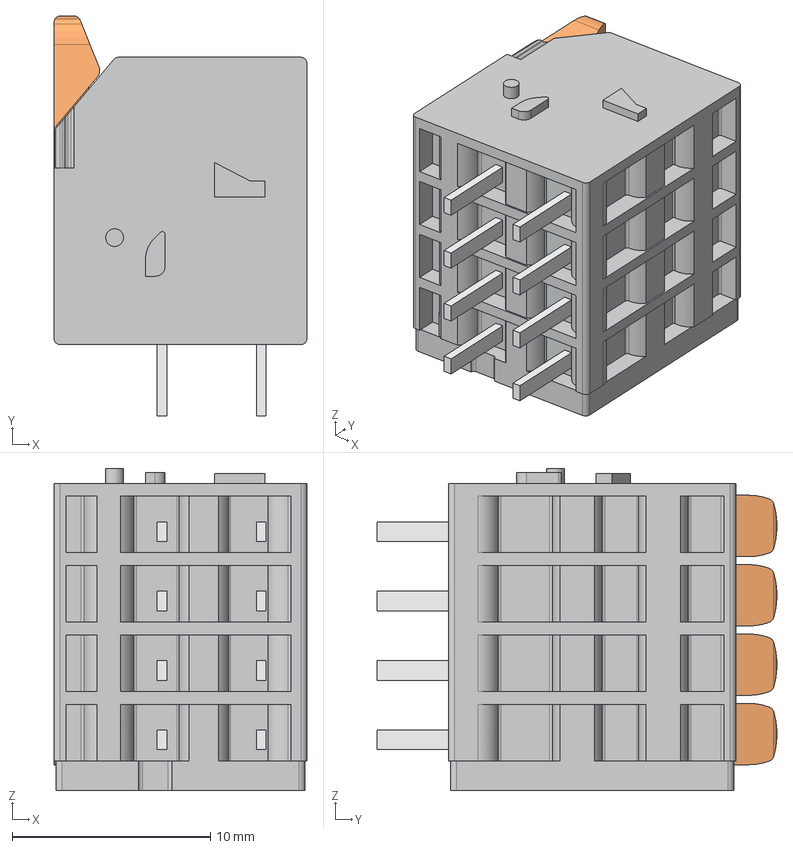
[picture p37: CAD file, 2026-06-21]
Hardware/ul_2601-3104/CadenasModel/2601-3104.stp
12.8 x 20.2 x 16.2 mm

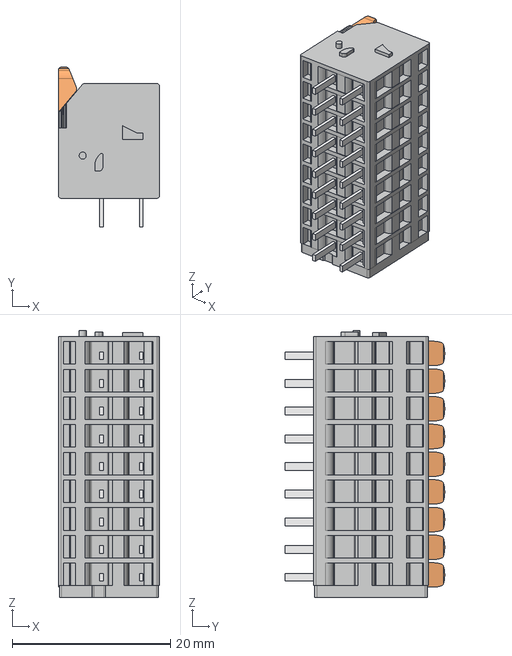
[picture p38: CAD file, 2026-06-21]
Hardware/ul_2601-3109/CadenasModel/2601-3109.stp
12.8 x 20.2 x 33.8 mm

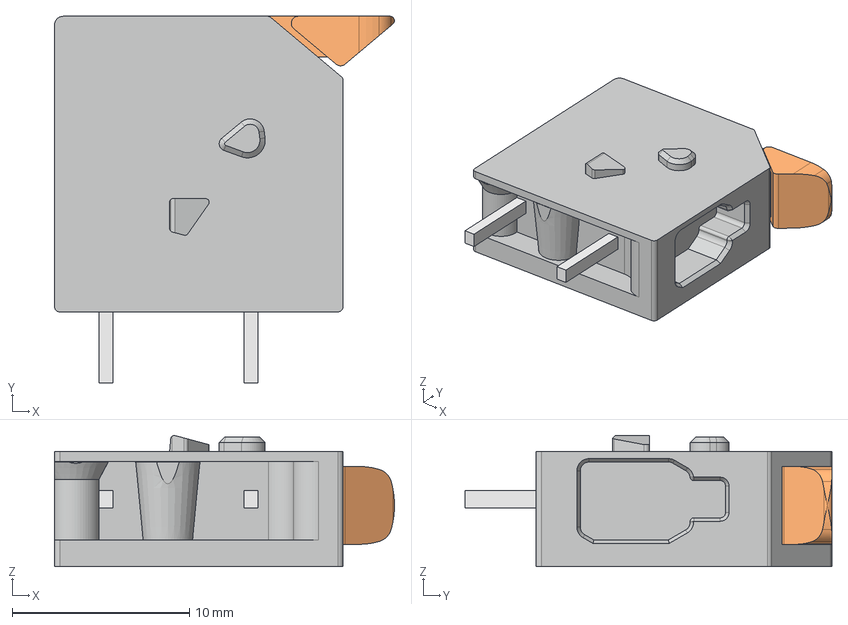
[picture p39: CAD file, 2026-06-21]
Hardware/ul_2604-1101/CadenasModel/2604-1101.stp
19.2 x 20.7 x 7.40 mm

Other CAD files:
Hardware/61300821821.stp
Hardware/61301021821.stp
Hardware/61302021821.stp
Hardware/BackUp/27_12_25/LIB_5360/5360/Allegro/5360.psm
Hardware/BackUp/27_12_25/LIB_5360/5360/DEHDL/5360/chips/chips.prt
Hardware/BackUp/27_12_25/LIB_SK_129_25,4_STS/SK_129_25,4_STS/DEHDL/sk_129_25_4_sts/chips/chips.prt
Hardware/C4AF9BW5100T3JK.step
Hardware/C4AQNLW5100M36J.step
Hardware/Inverter_Digi.step
Hardware/LIB_5360/5360/Allegro/5360.psm
Hardware/LIB_5360/5360/DEHDL/5360/chips/chips.prt
Hardware/LIB_SK_129_25,4_STS/SK_129_25,4_STS/DEHDL/sk_129_25_4_sts/chips/chips.prt
Hardware/PE-53117NL--3DModel-STEP-56544.STEP
Hardware/PPPC082LFBN-RC.STEP
Hardware/PPPC172LFBN-RC.STEP
Hardware/PPTC021LFBN-RC.STEP
Hardware/REC30K-2415DZ--3DModel-STEP-56544.STEP
Hardware/Relay_OMRON_P2RF-05-E.step
Hardware/SCF31B-180-S1R7A013J.step
Hardware/VM10_MVM10_stp.stp
Hardware/ul_2604-3102/CadenasModel/2604-3102.stp
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

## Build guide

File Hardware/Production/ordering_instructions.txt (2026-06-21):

Ordering Instructions:
Panel dimensions: 0.00 x 0.00 mm.
Solder Mask: Red (Default)
Silkscreen: White (Default)
Layers: 2
Finish: HASL Lead-free (Default)
Thickness: 1.6mm (Default)
Copper weight: 1oz (Default)

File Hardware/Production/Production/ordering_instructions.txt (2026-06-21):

Ordering Instructions:
Panel dimensions: 91.50 x 131.10 mm.
Solder Mask: Red (Default)
Silkscreen: White (Default)
Layers: 2
Finish: HASL Lead-free (Default)
Thickness: 1.6mm (Default)
Copper weight: 1oz (Default)

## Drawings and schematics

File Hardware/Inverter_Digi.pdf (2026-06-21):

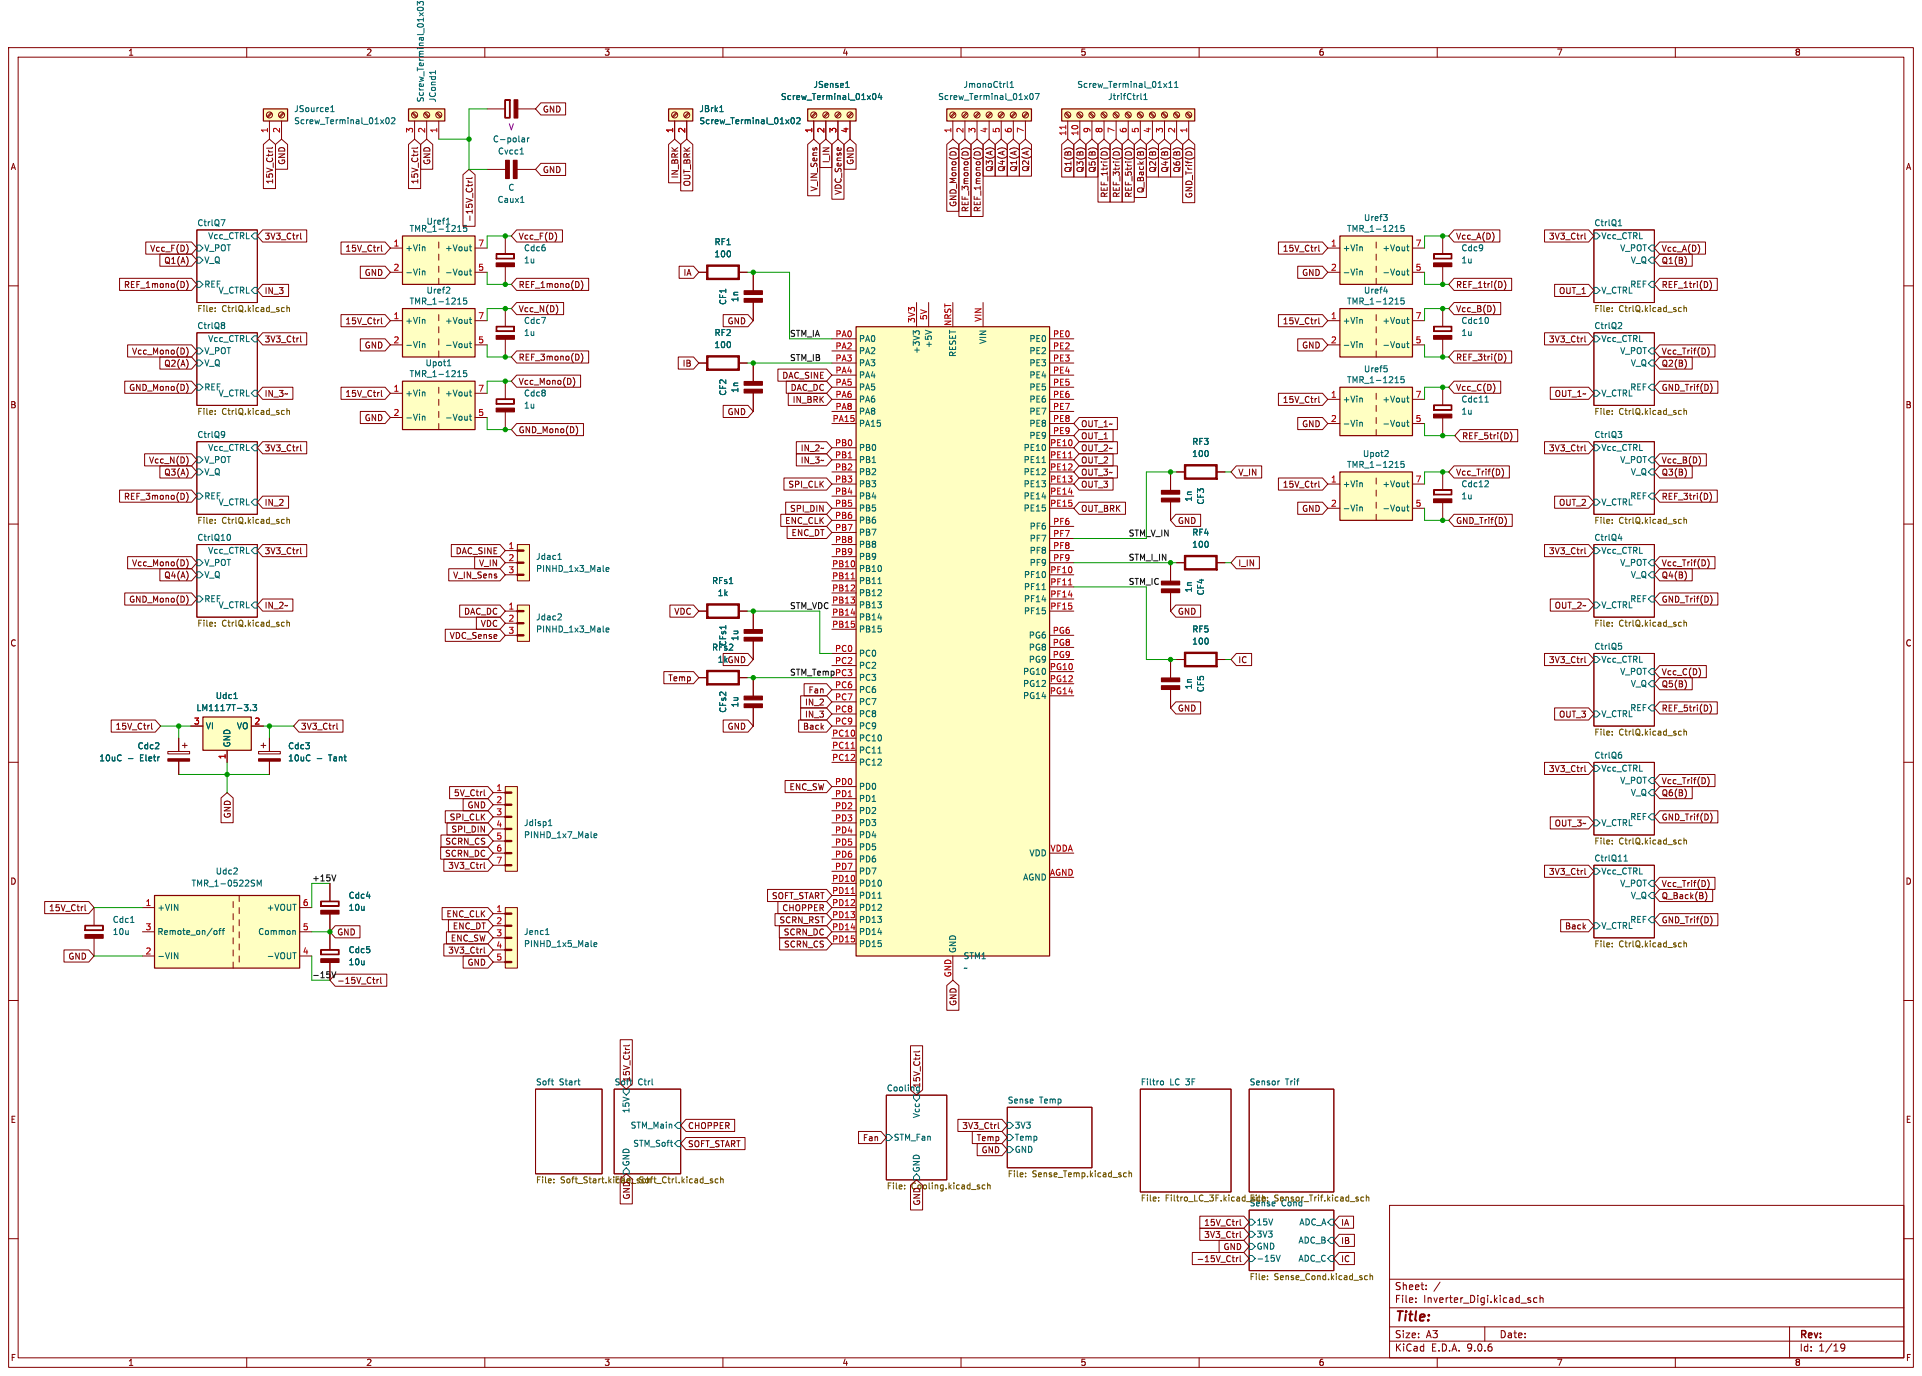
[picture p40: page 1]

I_IN GND GND GND 15V_Ctrl Fan

Sense Cond File: Sense_Cond.kicad_sch Sensor Trif File: Sensor_Trif.kicad_sch

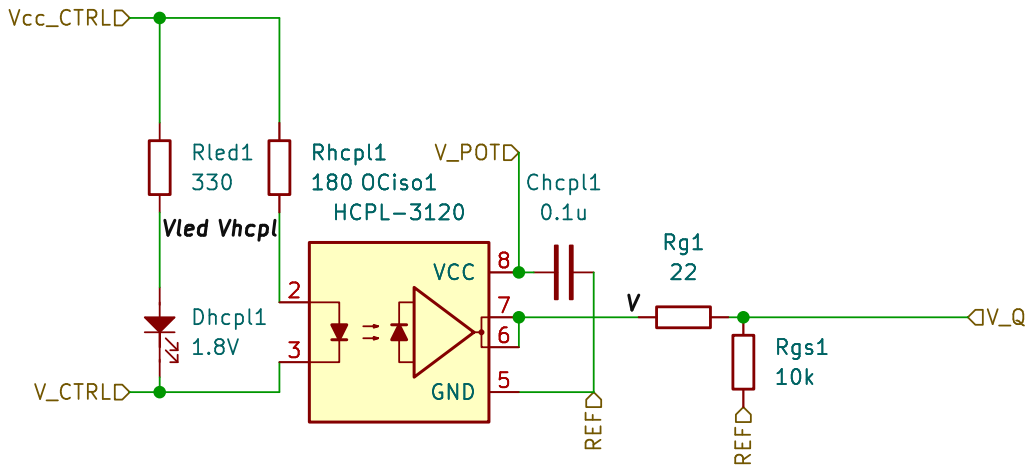
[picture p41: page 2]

Id: 2/19 Title: File: CtrlQ.kicad_sch Sheet: /CtrlQ11/

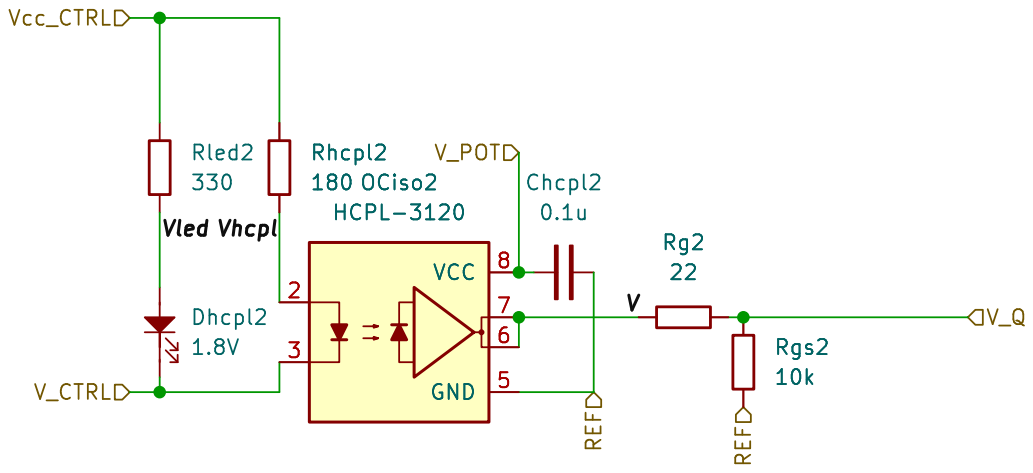
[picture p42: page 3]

Id: 17/19 Title: File: CtrlQ.kicad_sch Sheet: /CtrlQ1/

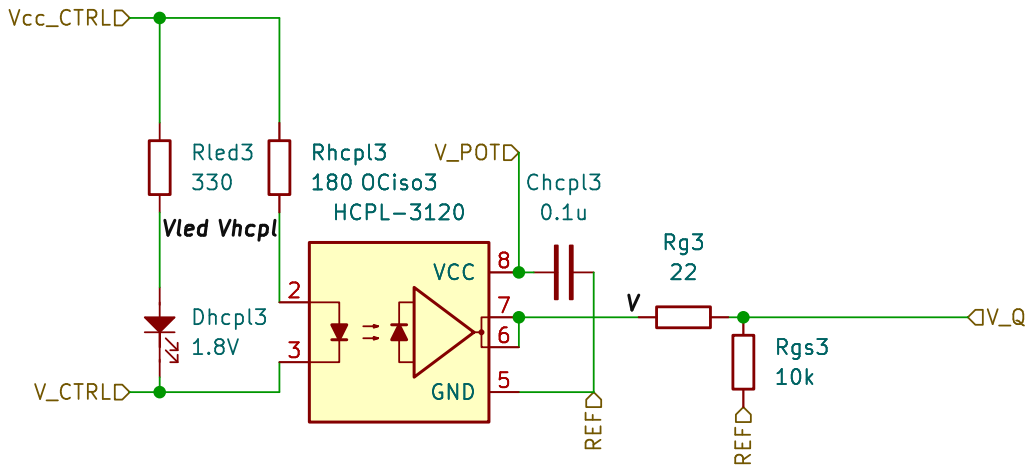
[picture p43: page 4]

Id: 19/19 Title: File: CtrlQ.kicad_sch Sheet: /CtrlQ2/

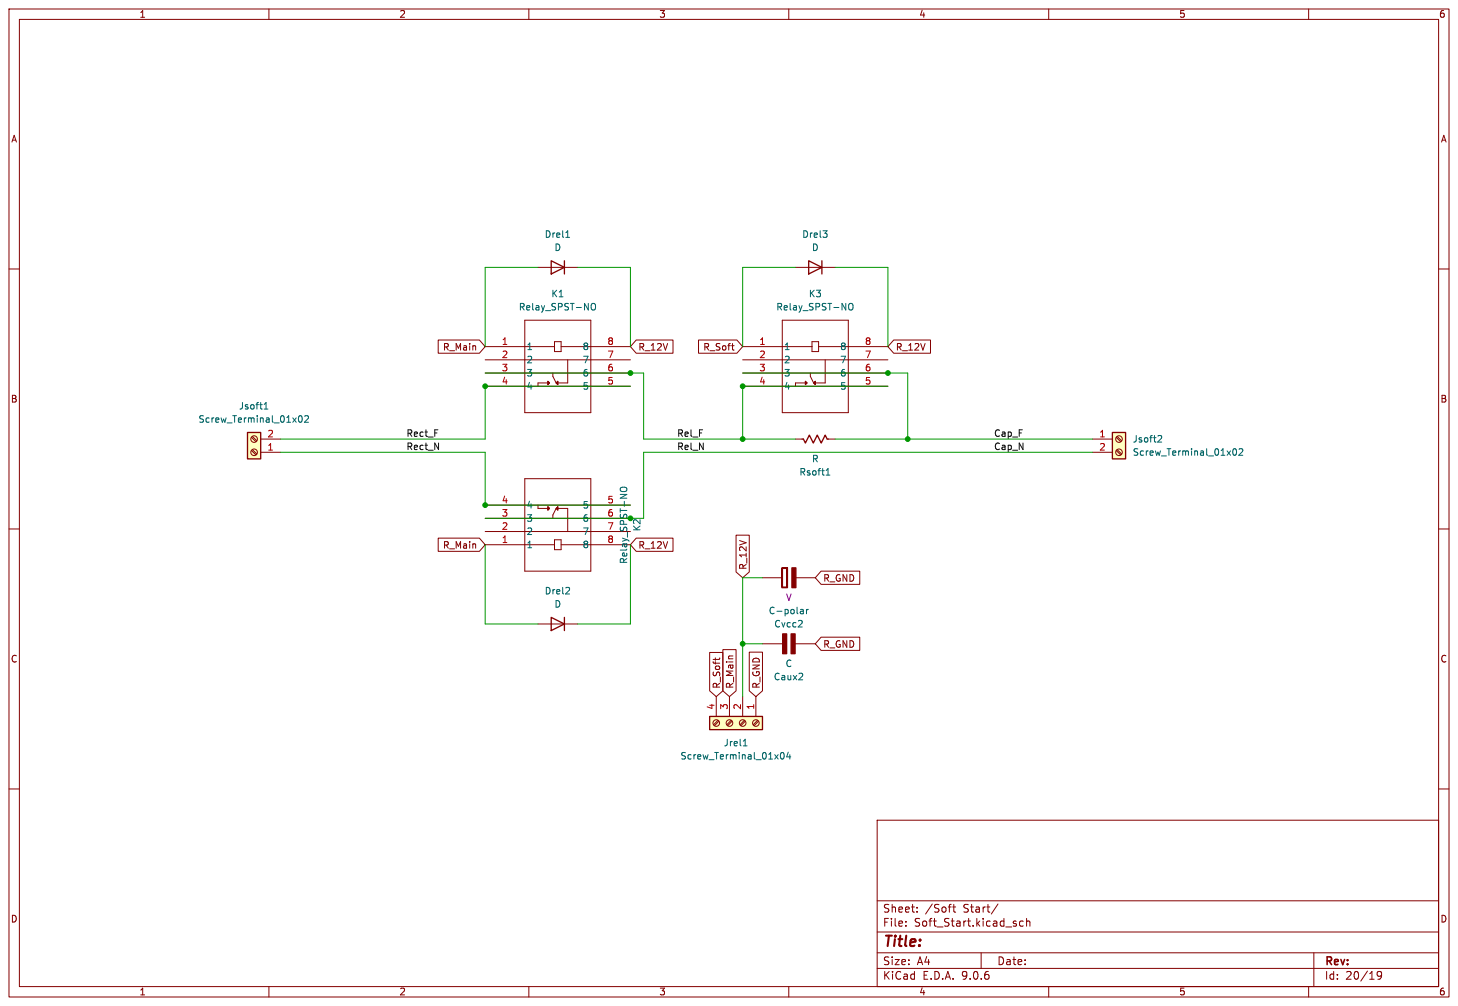
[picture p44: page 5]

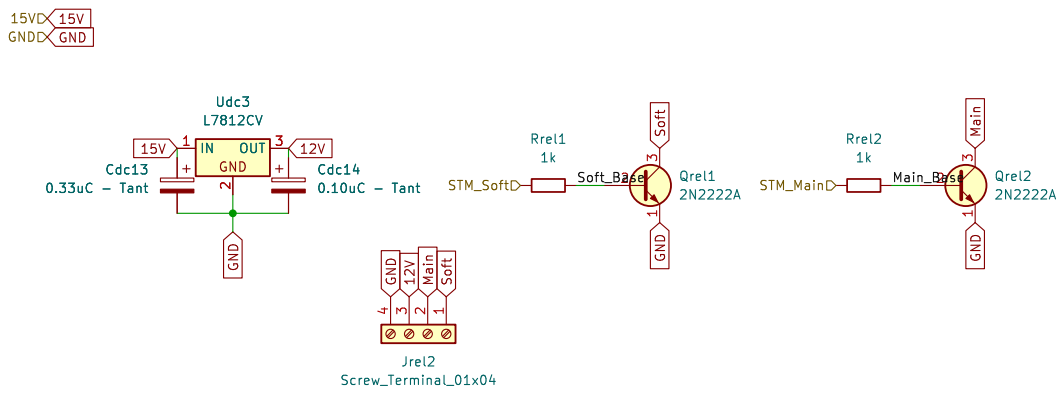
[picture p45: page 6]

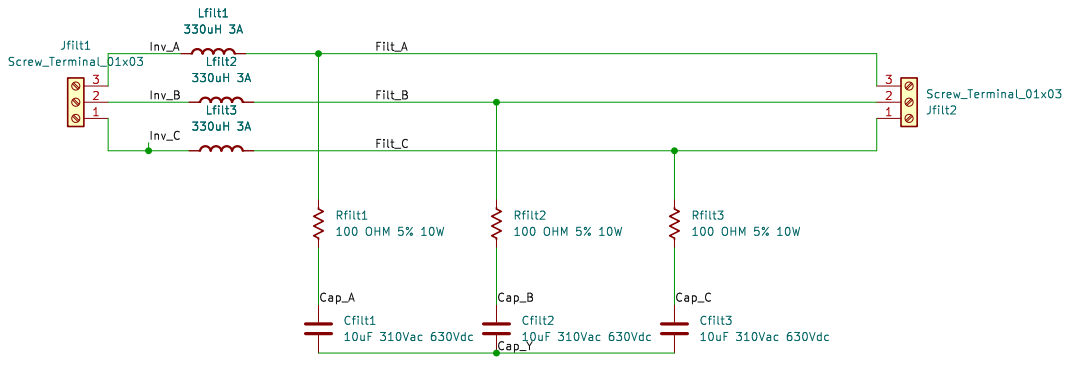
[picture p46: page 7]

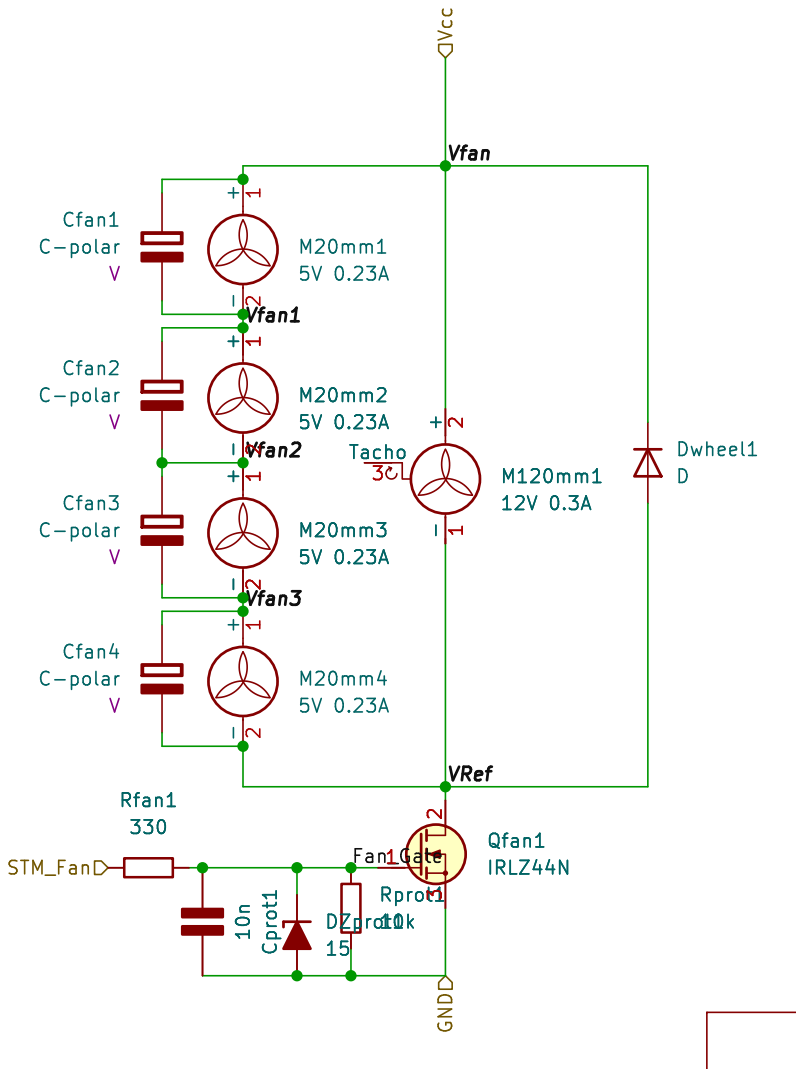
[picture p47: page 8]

Id: 22/19 Title: File: Cooling.kicad_sch Sheet: /Cooling/ Rfan1

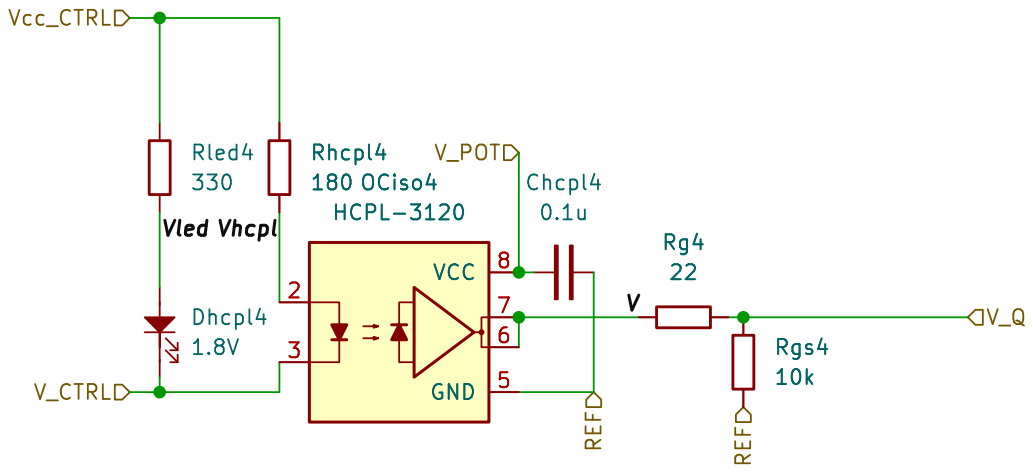
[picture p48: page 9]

Id: 22/19 Title: File: CtrlQ.kicad_sch Sheet: /CtrlQ3/

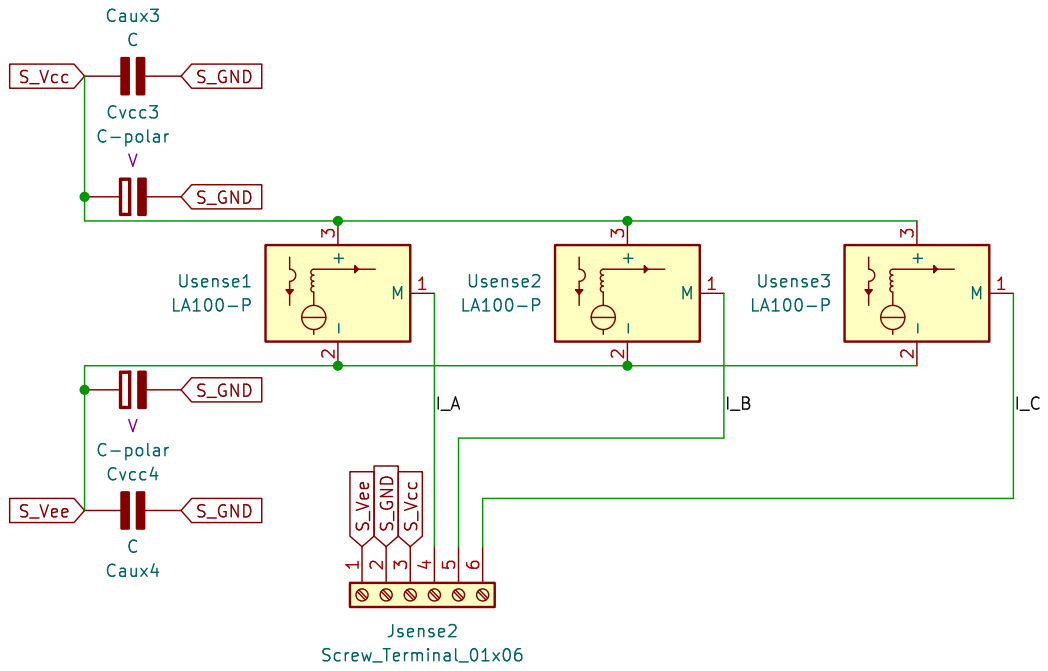
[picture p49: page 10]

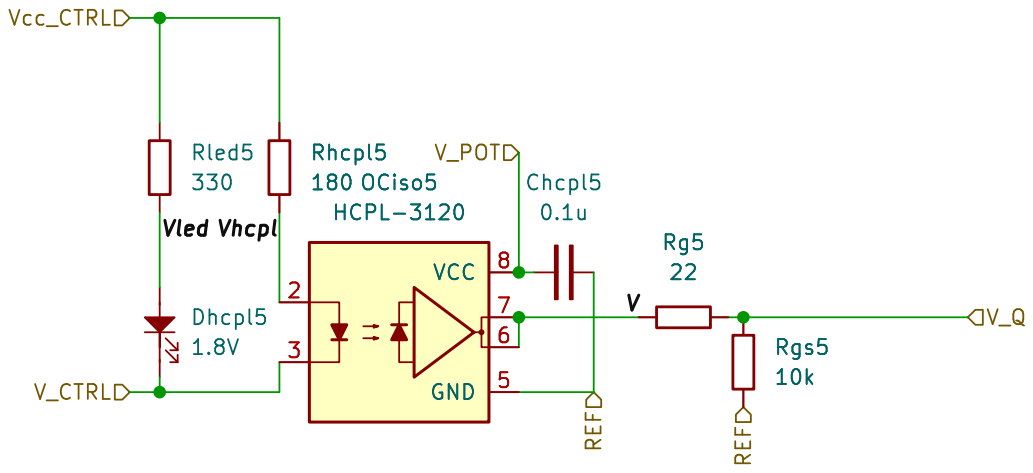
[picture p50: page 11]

Id: 23/19 Title: File: CtrlQ.kicad_sch Sheet: /CtrlQ4/

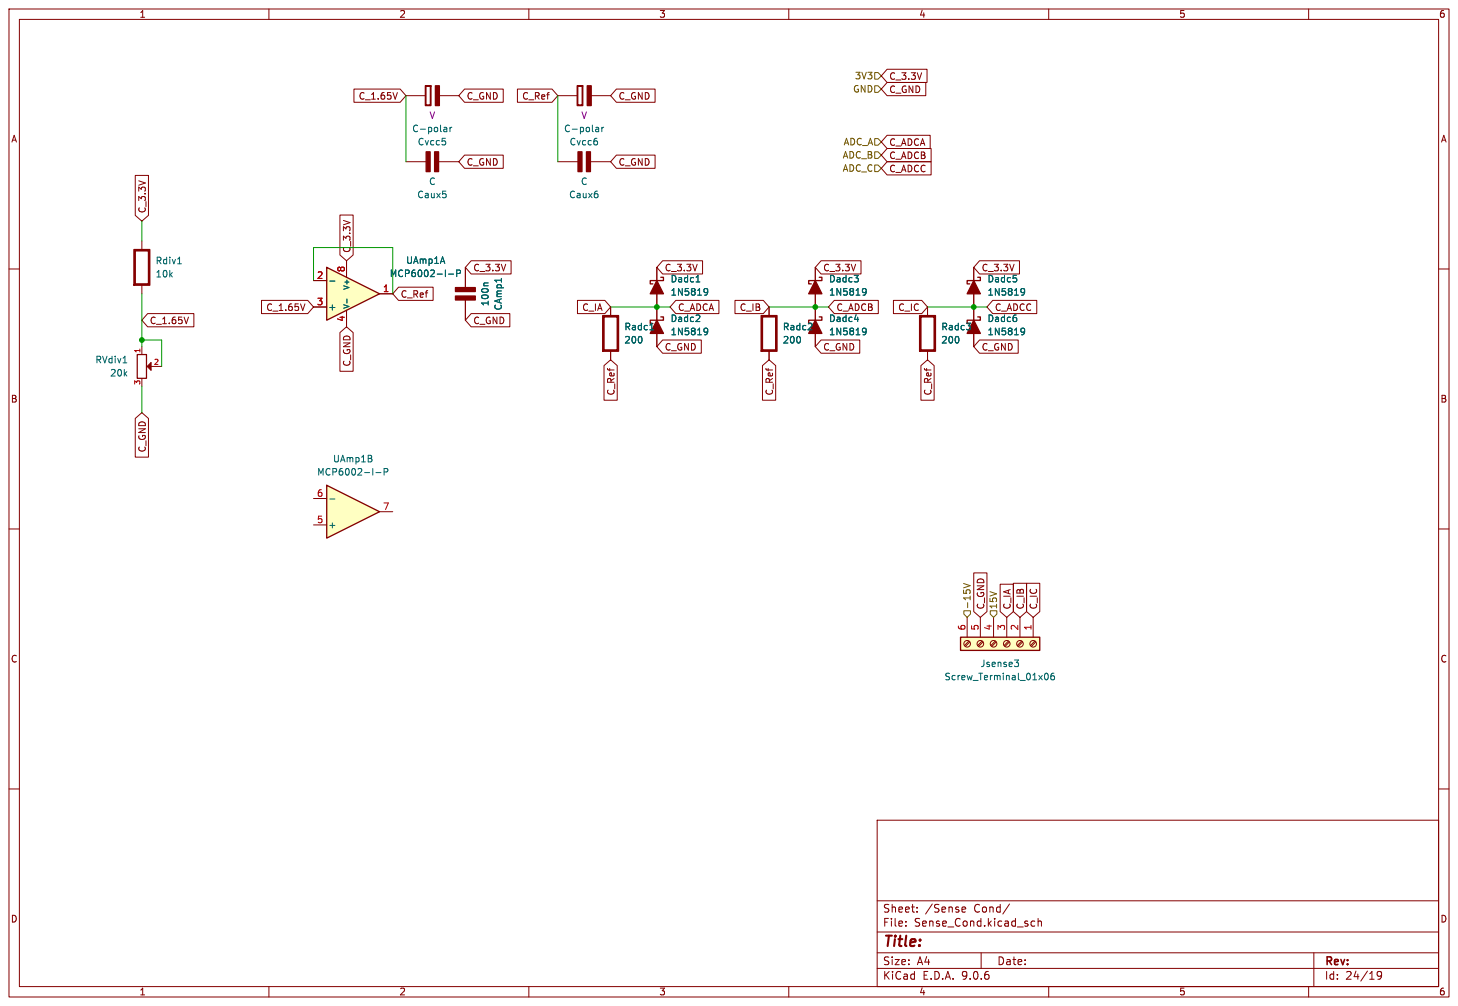
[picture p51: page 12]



Id: 26/19 Title: File: CtrlQ.kicad_sch Sheet: /CtrlQ5/


Id: 27/19 Title: File: CtrlQ.kicad_sch Sheet: /CtrlQ6/


Id: 28/19 Title: File: CtrlQ.kicad_sch Sheet: /CtrlQ7/


Id: 29/19 Title: File: CtrlQ.kicad_sch Sheet: /CtrlQ8/


Id: 30/19 Title: File: CtrlQ.kicad_sch Sheet: /CtrlQ9/


Id: 31/19 Title: File: CtrlQ.kicad_sch Sheet: /CtrlQ10/

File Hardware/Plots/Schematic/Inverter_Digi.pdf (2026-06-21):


I_IN GND GND GND 15V_Ctrl Fan

REF Vcc_CTRL CtrlQ11 File: CtrlQ.kicad_sch 15V GND STM_Main STM_Soft Soft Ctrl File: Soft_Ctrl.kicad_sch

File: Filtro_LC_3F.kicad_sch Soft Start File: Soft_Start.kicad_sch

Sense Cond File: Sense_Cond.kicad_sch Sensor Trif File: Sensor_Trif.kicad_sch


Id: 2/19 Title: File: CtrlQ.kicad_sch Sheet: /CtrlQ11/


Id: 17/19 Title: File: CtrlQ.kicad_sch Sheet: /CtrlQ1/


Id: 19/19 Title: File: CtrlQ.kicad_sch Sheet: /CtrlQ2/





Id: 22/19 Title: File: Cooling.kicad_sch Sheet: /Cooling/ Rfan1


Id: 22/19 Title: File: CtrlQ.kicad_sch Sheet: /CtrlQ3/



Id: 23/19 Title: File: CtrlQ.kicad_sch Sheet: /CtrlQ4/




Id: 26/19 Title: File: CtrlQ.kicad_sch Sheet: /CtrlQ5/


Id: 27/19 Title: File: CtrlQ.kicad_sch Sheet: /CtrlQ6/


Id: 28/19 Title: File: CtrlQ.kicad_sch Sheet: /CtrlQ7/


Id: 29/19 Title: File: CtrlQ.kicad_sch Sheet: /CtrlQ8/


Id: 30/19 Title: File: CtrlQ.kicad_sch Sheet: /CtrlQ9/


Id: 31/19 Title: File: CtrlQ.kicad_sch Sheet: /CtrlQ10/







































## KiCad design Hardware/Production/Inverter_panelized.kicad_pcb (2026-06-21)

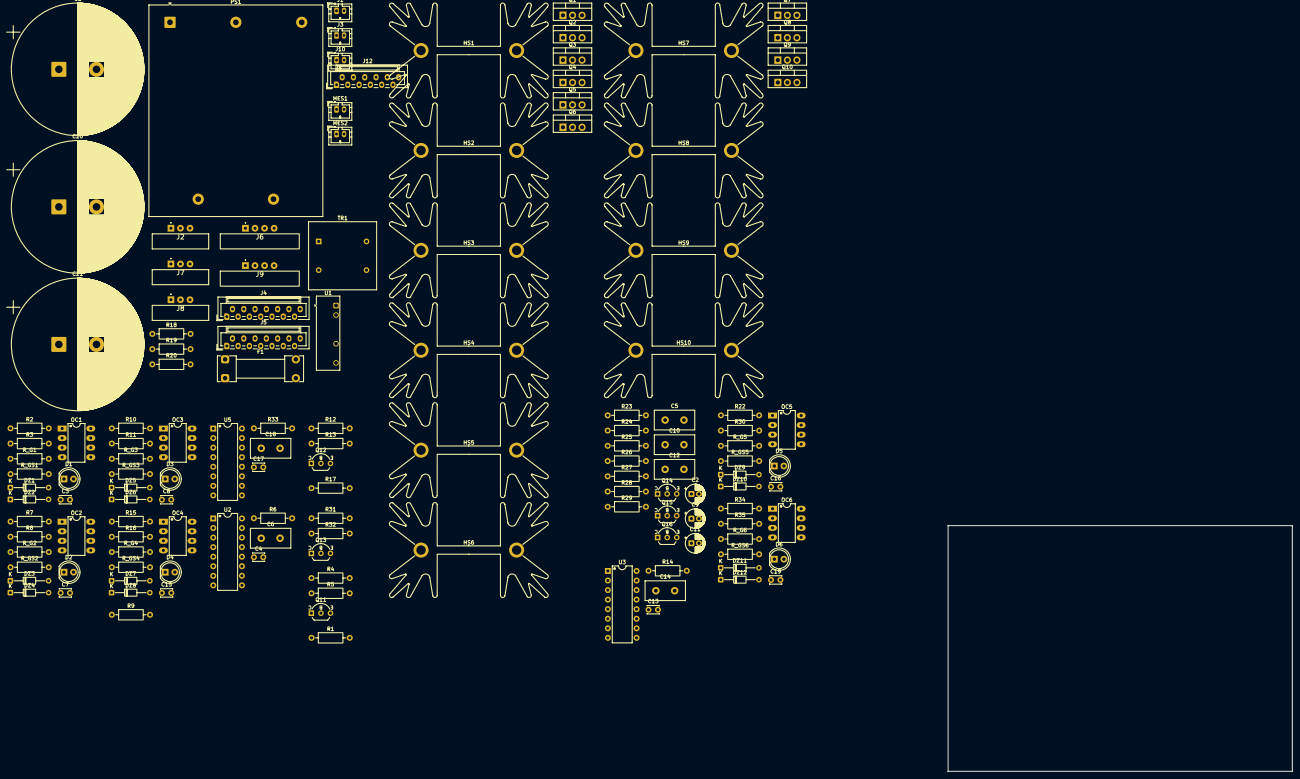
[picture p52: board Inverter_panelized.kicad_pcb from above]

Board: 2 copper layers, 91.5 x 65.3 mm, 137 parts (0 on the bottom side), 81 nets, no tracks yet.

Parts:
C1, C20, C21: 1000u350V; CP_Radial_D35.0mm_P10.00mm_SnapIn
C2, C9, C11: 1u; CP_Radial_D5.0mm_P2.00mm
C3, C7, C8, C15, C16, C19: 0.1u; C_Disc_D3.0mm_W2.0mm_P2.50mm
C4, C13, C17: Capacitor_NP; C_Disc_D3.0mm_W2.0mm_P2.50mm
C5, C10, C12: 22n; C_Disc_D10.5mm_W5.0mm_P5.00mm
C6, C14, C18: 100n; C_Disc_D10.5mm_W5.0mm_P5.00mm
D1, D2, D3, D4, D5, D6: LED; LED_D5.0mm
DZ1, DZ2, DZ3, DZ4, DZ5, DZ6, DZ7, DZ8, DZ9, DZ10, DZ11, DZ12: D_Zener_Generic; D_DO-34_SOD68_P10.16mm_Horizontal
F1: Fuse; Fuseholder_Clip-5x20mm_Littelfuse_111_Lateral_P18.80x5.00mm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
HS1, HS2, HS3, HS4, HS5, HS6, HS7, HS8, HS9, HS10: Heatsink_Pad; Heatsink_Fischer_SK129-STS_42x25mm_2xDrill2.5mm
J1, J3, J10: Conn_01x02_Socket; JST_PH_B2B-PH-K_1x02_P2.00mm_Vertical
J2, J7, J8: Conn_01x03_Pin; 3pin_Magnet_5360
J4, J5: Conn_01x14_Socket; JST_ZE_B14B-ZESK-D_1x14_P1.50mm_Vertical
J6, J9: Conn_01x04_Pin; 4pin_Magnet_5358
J12: Conn_01x12_Socket; JST_ZE_B12B-ZESK-D_1x12_P1.50mm_Vertical
MES1: Ammeter_DC; JST_PH_B2B-PH-K_1x02_P2.00mm_Vertical
MES2: Voltmeter_DC; JST_PH_B2B-PH-K_1x02_P2.00mm_Vertical
OC1, OC2, OC3, OC4, OC5, OC6: HCPL-3120; DIP-8_W7.62mm_LongPads
PS1: VTX-214-015-115; Converter_ACDC_Vigortronix_VTX-214-015-1xx_THT
Q1, Q2, Q3, Q4, Q5, Q6, Q7, Q8, Q9, Q10: 600V40A; TO-220-3_Vertical
Q11, Q12, Q13: BC546; TO-92_Inline_Wide_CBE
Q14, Q15, Q16: BC547; TO-92_Inline_Wide_CBE
R1, R2, R3, R4, R5, R6, R7, R8, R9, R10, R11, R12, R13, R14, R15, R16, R17, R18, R19, R20, R22, R30, R31, R32, R33, R34, R35: Resistor; R_Axial_DIN0207_L6.3mm_D2.5mm_P10.16mm_Horizontal
R23, R25, R27: 10k; R_Axial_DIN0207_L6.3mm_D2.5mm_P10.16mm_Horizontal
R24, R26, R28, R29: 2.2k; R_Axial_DIN0207_L6.3mm_D2.5mm_P10.16mm_Horizontal
R_G1, R_G2, R_G3, R_G4, R_G5, R_G6: Resistor; R_Axial_DIN0207_L6.3mm_D2.5mm_P10.16mm_Horizontal
R_GS1, R_GS2, R_GS3, R_GS4, R_GS5, R_GS6: Resistor; R_Axial_DIN0207_L6.3mm_D2.5mm_P10.16mm_Horizontal
TR1: 1:1; Transformer_NF_ETAL_1-1_P1200
U1: TMR_1-1215; Converter_DCDC_TRACO_TEA1-xxxxHI_THT
U2, U3, U5: TL494; DIP-16_W7.62mm

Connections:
/AC+: F1.2, PS1.3 (L), Q7.2 (C), Q9.2 (C)
/CtrlA: C5.1 (+), J7.1, J8.1, R1.2, R2.2, R3.2, R4.1, U2.3 (FB), U2.8 (C1), U2.11 (C2)
/CtrlB: C10.1 (+), J7.2, J8.2, R9.2, R10.2, R11.2, R12.1, U3.3 (FB), U3.8 (C1), U3.11 (C2)
/CtrlC: C12.1 (+), J7.3, J8.3, R17.2, R22.2, R30.2, R31.1, U5.3 (FB), U5.8 (C1), U5.11 (C2)
/CtrlRamo1/CtrlQ1/V: OC1.6, OC1.7, R_G1.2
/CtrlRamo1/CtrlQ1/Vhcpl: OC1.2, R3.1
/CtrlRamo1/CtrlQ1/Vled: D1.2, R2.1
/CtrlRamo1/CtrlQ2/V: OC2.6, OC2.7, R_G2.2
/CtrlRamo1/CtrlQ2/Vhcpl: OC2.2, R8.1
/CtrlRamo1/CtrlQ2/Vled: D2.2, R7.1
/CtrlRamo1/~Vctrl: Q11.1 (C), R5.1, R7.2, R8.2
/CtrlRamo2/CtrlQ1/V: OC3.6, OC3.7, R_G3.2
/CtrlRamo2/CtrlQ1/Vhcpl: OC3.2, R11.1
/CtrlRamo2/CtrlQ1/Vled: D3.2, R10.1
/CtrlRamo2/CtrlQ2/V: OC4.6, OC4.7, R_G4.2
/CtrlRamo2/CtrlQ2/Vhcpl: OC4.2, R16.1
/CtrlRamo2/CtrlQ2/Vled: D4.2, R15.1
/CtrlRamo2/~Vctrl: Q12.1 (C), R13.1, R15.2, R16.2
/CtrlRamo3/CtrlQ1/V: OC5.6, OC5.7, R_G5.2
/CtrlRamo3/CtrlQ1/Vhcpl: OC5.2, R30.1
/CtrlRamo3/CtrlQ1/Vled: D5.2, R22.1
/CtrlRamo3/CtrlQ2/V: OC6.6, OC6.7, R_G6.2
/CtrlRamo3/CtrlQ2/Vhcpl: OC6.2, R35.1
/CtrlRamo3/CtrlQ2/Vled: D6.2, R34.1
/CtrlRamo3/~Vctrl: Q13.1 (C), R32.1, R34.2, R35.2
/DC+_amp: MES1.2 (+), Q1.2 (C), Q3.2 (C), Q5.2 (C)
/GND: J6.4, R29.2
/Oscilador/B_A: C2.1 (+), Q14.2 (B), R23.2
/Oscilador/B_B: C9.1 (+), Q15.2 (B), R25.2
/Oscilador/B_C: C11.1 (+), Q16.2 (B), R27.2
/Oscilador/C_A: C5.2 (-), Q14.1 (C), R24.1, R25.1
/Oscilador/C_B: C10.2 (-), Q15.1 (C), R26.1, R27.1
/Oscilador/C_C: C12.2 (-), Q16.1 (C), R23.1, R28.1, R29.1
/Oscilador/E: C2.2 (-), C9.2 (-), C11.2 (-), Q14.3 (E), Q15.3 (E), Q16.3 (E)
/Q1: DZ1.1 (K), J4.6, J5.6, J12.4, Q1.1 (G), Q7.1 (G), R_G1.1, R_GS1.1
/Q2: DZ3.1 (K), J4.5, J5.5, J12.3, Q2.1 (G), Q8.1 (G), R_G2.1, R_GS2.1
/Q3: DZ5.1 (K), J4.4, J5.4, J12.2, Q3.1 (G), Q9.1 (G), R_G3.1, R_GS3.1
/Q4: DZ7.1 (K), J4.3, J5.3, J12.1, Q4.1 (G), Q10.1 (G), R_G4.1, R_GS4.1
/Q5: DZ9.1 (K), J4.2, J5.2, Q5.1 (G), R_G5.1, R_GS5.1
/Q6: DZ11.1 (K), J4.1, J5.1, Q6.1 (G), R_G6.1, R_GS6.1
/Rede+: J1.1, J1.2, TR1.1, TR1.2
/Trans-Fuse: F1.1, TR1.4
/Vref: R18.2, R19.2, R20.2, R24.2, R26.2, R28.2
/Vref1: J6.1, R18.1
/Vref2: J6.2, R19.1
/Vref3: J6.3, R20.1
GND_Ctrl(A): J3.1, J12.7, PS1.5 (DC-)
GND_Ctrl(D): C4.1, C6.2 (-), C13.1, C14.2 (-), C17.1, C18.2 (-), D1.1, D2.1, D3.1, D4.1, D5.1, D6.1, J9.4, J10.1, OC1.3, OC2.3, OC3.3, OC4.3, OC5.3, OC6.3, Q11.3 (E), Q12.3 (E), Q13.3 (E), R6.1, R14.1, R33.1, U1.2 (-Vin), U2.1 (1IN+), U2.2 (1IN-), U2.4 (DTC), U2.7 (GND), U2.9 (E1), U2.10 (E2), U2.15 (2IN-), U2.16 (2IN+), U3.1 (1IN+), U3.2 (1IN-), U3.4 (DTC), U3.7 (GND), U3.9 (E1), U3.10 (E2), U3.15 (2IN-), U3.16 (2IN+), U5.1 (1IN+), U5.2 (1IN-), U5.4 (DTC), U5.7 (GND), U5.9 (E1), U5.10 (E2), U5.15 (2IN-), U5.16 (2IN+)
GND_Pot(B): J4.7, J4.8, J4.10, J4.12, J12.10, MES2.1 (-), Q2.3 (E), Q4.3 (E), Q6.3 (E), Q9.3 (E), Q10.2 (C)
GND_Pot(D): J5.7, U1.5 (-Vout)
unnamed: DZ1.2 (A), DZ2.2 (A)
unnamed: DZ3.2 (A), DZ4.2 (A)
unnamed: DZ5.2 (A), DZ6.2 (A)
unnamed: DZ7.2 (A), DZ8.2 (A)
unnamed: DZ9.2 (A), DZ10.2 (A)
unnamed: DZ11.2 (A), DZ12.2 (A)
unnamed: Q11.2 (B), R4.2
unnamed: Q12.2 (B), R12.2
unnamed: Q13.2 (B), R31.2
unnamed: C4.2, U2.5 (CT)
unnamed: R6.2, U2.6 (RT)
unnamed: C13.2, U3.5 (CT)
unnamed: R14.2, U3.6 (RT)
unnamed: C17.2, U5.5 (CT)
unnamed: R33.2, U5.6 (RT)
REF_1mono(B): J12.12, MES1.1 (-), MES2.2 (+), Q7.3 (E), Q8.2 (C)
REF_1tri(B): C1.1, C21.2, J2.3, J4.13, Q1.3 (E), Q2.2 (C)
REF_1tri(D): C3.2, DZ2.1 (K), J5.13, OC1.5 (GND), R_GS1.2
REF_2tri(D): C7.2, DZ4.1 (K), J5.12, OC2.5 (GND), R_GS2.2
REF_3tri(B): C1.2, C20.1, J2.2, J4.11, Q3.3 (E), Q4.2 (C)
REF_3tri(D): C8.2, DZ6.1 (K), J5.11, OC3.5 (GND), R_GS3.2
REF_4mono(B): J12.9, J12.11, PS1.2 (N), Q8.3 (E), Q10.3 (E), TR1.3
REF_4tri(D): C15.2, DZ8.1 (K), J5.10, OC4.5 (GND), R_GS4.2
REF_5tri(B): C20.2, C21.1, J2.1, J4.9, Q5.3 (E), Q6.2 (C)
REF_5tri(D): C16.2, DZ10.1 (K), J5.9, OC5.5 (GND), R_GS5.2
REF_6tri(D): C19.2, DZ12.1 (K), J5.8, OC6.5 (GND), R_GS6.2
Vcc_Ctrl(A): J3.2, J12.6, PS1.4 (DC+)
Vcc_Ctrl(D): C6.1 (+), C14.1 (+), C18.1 (+), J10.2, R1.1, R5.2, R9.1, R13.2, R17.1, R32.2, U1.1 (+Vin), U2.12 (VCC), U3.12 (VCC), U5.12 (VCC)
Vcc_Pot(D): C3.1, C7.1, C8.1, C15.1, C16.1, C19.1, OC1.8 (VCC), OC2.8 (VCC), OC3.8 (VCC), OC4.8 (VCC), OC5.8 (VCC), OC6.8 (VCC), U1.7 (+Vout)
Vref1(D): J9.1, U2.14 (REF)
Vref2(D): J9.2, J9.3, U3.14 (REF)

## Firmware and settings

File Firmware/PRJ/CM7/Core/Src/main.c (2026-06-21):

/* USER CODE BEGIN Header */
/******************************************************************************
 * @file           : Arquitetura_Projeto.txt / main.c
 * @brief          : Controlo Digital de Variador de Velocidade e Retificador AFE
 * @author         : Nuno Costa (a107069) e Afonso Carvalho (a107058)
 * @institution    : Universidade do Minho
 * @date           : Junho de 2026
 * * @description    :
 * Este projeto implementa o controlo digital em tempo real (25 kHz) de um
 * motor trifásico usando a técnica SPWM e curva V/f constante, alimentado
 * por um Retificador Ativo (AFE - Active Front End) com controlo de histerese.
 * O sistema opera num STM32H7 e conta ainda com telemetria SCADA, Interface
 * local e um Simulador incorporado.
 *
 * * ============================================================================
 * ESTRUTURA DE FICHEIROS E MÓDULOS
 * ============================================================================
 * * [ CORE ]
 * > main.c / main.h
 * Gere a máquina de estados principal, inicializa os
 * periféricos e implementa os três domínios de tempo de execução:
 * - Prioridade Máxima: Interrupções de segurança e paragem de emergência.
 * - 25 kHz (Tempo Real): Controlo físico de potência, processamento ADC e algoritmos PI.
 * - 10 Hz (Assíncrono): Atualização de ecrã e transmissão de telemetria.
 *
 * * [ POTÊNCIA E CONTROLO ]
 * > PWM.c / PWM.h
 * Módulo de Eletrónica de Potência. Executa a malha PLL (Phase-Locked Loop),
 * o controlo PI de tensão do barramento DC e o controlo de corrente
 * (histerese) do AFE. Gera a modulação SPWM trifásica defasada a 120º e a rampa
 * de aceleração para o inversor do motor.
 *
 * * [ SENSORES E SINAIS ]
 * > DD_ADC.c / DD_ADC.h
 * Device Driver de Abstração de Hardware. Gere o mapeamento de memória SRAM
 * específico do hardware (D2/D3) e a transferência direta de memória (DMA e BDMA)
 * dos conversores ADC1 e ADC3.
 * * > SENSE.c / SENSE.h
 * Módulo de Processamento de Sinal. Converte os valores RAW dos conversores
 * em grandezas físicas reais (Volts, Amperes, Celsius) e processa os
 * cálculos True RMS (janela de 20ms). Age como intermediário para a injeção
 * de dados do simulador.
 *
 * * [ INTERFACE E TELEMETRIA ]
 * > PANEL.c / PANEL.h
 * Human-Machine Interface (HMI). Controla o ecrã ST7789 via comunicação
 * SPI e gere a navegação das tabs de interface e edição de setpoints através
 * de um Encoder Rotativo com debounce de hardware.
 * * > INTER.c / INTER.h
 * Módulo de Comunicação. Compila a telemetria completa do sistema num
 * formato JSON otimizado e gere o envio não-bloqueante dos pacotes via
 * UART/DMA para o *dashboard* Node-RED.
 *
 * * [ VALIDAÇÃO E TESTE ]
 * > SIMUL.c / SIMUL.h
 * Hardware-in-the-Loop (Digital Twin). Emula matematicamente a impedância da
 * rede elétrica, a resposta física do condensador do barramento DC e o consumo
 * indutivo do motor. Injeta os sinais virtuais via DAC e no código para validação
 * do controlo sem potência real aplicada.
 * ******************************************************************************/
/* USER CODE END Header */
/* Includes ------------------------------------------------------------------*/
#include "main.h"
#include "adc.h"
#include "bdma.h"
#include "dac.h"
#include "dma.h"
#include "spi.h"
#include "tim.h"
#include "usart.h"
#include "gpio.h"

/* USER CODE BEGIN Includes */
//--------------------------------------------------------------------------
#include <stdio.h>
#include <string.h>
#include "st7789.h"
#include "PWM.h"
#include "SENSE.h"
#include "SIMUL.h"
#include "INTER.h"
#include "PANEL.h"
//--------------------------------------------------------------------------
/* USER CODE END Includes */

/* USER CODE BEGIN PD */

#ifndef HSEM_ID_0
#define HSEM_ID_0 (0U) /* HW semaphore 0*/
#endif

/* USER CODE END PD */


void SystemClock_Config(void);
void PeriphCommonClock_Config(void);
/* USER CODE BEGIN 0 */
//--------------------------------------------------------------------------
/* Variáveis de Máquina de Estados Global */
volatile uint8_t afe_user_enable = 0;
volatile uint8_t afe_control_enable = 0;
volatile uint8_t afe_control_stage = 0;

volatile int tim = 0;
volatile int Emerg = 0;

int system_fault = 0;
int fault_source = 0;
volatile uint8_t inverter_enable = 0;
//--------------------------------------------------------------------------
/* USER CODE END 0 */

/**
  * @brief  The application entry point.
  * @retval int
  */
int main(void)
{

/* USER CODE BEGIN Boot_Mode_Sequence_0 */
  int32_t timeout;
/* USER CODE END Boot_Mode_Sequence_0 */

/* USER CODE BEGIN Boot_Mode_Sequence_1 */
  /* Wait until CPU2 boots and enters in stop mode or timeout*/
  timeout = 0xFFFF;
  while((__HAL_RCC_GET_FLAG(RCC_FLAG_D2CKRDY) != RESET) && (timeout-- > 0));
  if ( timeout < 0 )
  {
  Error_Handler();
  }
/* USER CODE END Boot_Mode_Sequence_1 */
  /* MCU Configuration--------------------------------------------------------*/

  /* Reset of all peripherals, Initializes the Flash interface and the Systick. */
  HAL_Init();

  /* Configure the system clock */
  SystemClock_Config();

  /* Configure the peripherals common clocks */
  PeriphCommonClock_Config();
/* USER CODE BEGIN Boot_Mode_Sequence_2 */
/* When system initialization is finished, Cortex-M7 will release Cortex-M4 by means of
HSEM notification */
/*HW semaphore Clock enable*/
__HAL_RCC_HSEM_CLK_ENABLE();
/*Take HSEM */
HAL_HSEM_FastTake(HSEM_ID_0);
/*Release HSEM in order to notify the CPU2(CM4)*/
HAL_HSEM_Release(HSEM_ID_0,0);
/* wait until CPU2 wakes up from stop mode */
timeout = 0xFFFF;
while((__HAL_RCC_GET_FLAG(RCC_FLAG_D2CKRDY) == RESET) && (timeout-- > 0));
if ( timeout < 0 )
{
Error_Handler();
}
/* USER CODE END Boot_Mode_Sequence_2 */

  /* Initialize all configured peripherals */
  MX_GPIO_Init();
  MX_DMA_Init();
  MX_BDMA_Init();
  MX_SPI1_Init();
  MX_USART3_UART_Init();
  MX_TIM1_Init();
  MX_TIM4_Init();
  MX_ADC3_Init();
  MX_TIM8_Init();
  MX_DAC1_Init();
  MX_ADC1_Init();
  MX_TIM6_Init();
  MX_TIM3_Init();
  /* USER CODE BEGIN 2 */
  //--------------------------------------------------------------------------
  /* Arranque Seguro Sequencial dos Sistemas Próprios */
  Panel_Init_Sequence();          // Lança a Interface Humana
  Sense_Init_DMA(&hadc1, &hadc3); // Lança o cérebro de Sensoreamento DMA
  DacSim_Init(&hdac1);            // Instancia os modelos de simulação na placa
  PWM_Start_All();                // Energiza todos os módulos de sinal PWM
  //--------------------------------------------------------------------------
  /* USER CODE END 2 */

  /* Infinite loop */
  /* USER CODE BEGIN WHILE */
  while (1)
    {
	  /* =========================================================
		 DOM�?NIO 1: ALARME E INTERRUPÇÕES F�?SICAS (Prioridade 1)
		 ========================================================= */
	  if (Emerg) {
		  PWM_Emergency_Stop();
		  PWM_AFE_PWM_Kill();
		  PWM_Set_Main_Contactor(0); // Abre a rede
		  system_fault = 1;
		  fault_source = 3; // O hardware ativou o BKIN

		  /* Cortar e desligar lógica humana */
		  afe_user_enable = 0;
		  afe_control_enable = 0;
		  afe_control_stage = 0;

		  Emerg = 0; // Desarma flag da interrupção
	  }

	  /* =========================================================
		 DOM�?NIO 2: TEMPO REAL 25 kHz (Prioridade 2)
		 ========================================================= */
	  if (tim) {
		  /* 1. Ciclo Físico -> Virtual -> Sensorial -> Defesa */
		  DacSim_Update_Grid_DC(&hdac1);
		  Simul_Update_Motor_Currents();
		  Sense_Process_Data();
		  Check_Safety();

		  /* 2. Passagem do mundo real para o espaço matemático */
		  float v_pg = Sense_Get_V_Grid_Inst();
		  float i_pg = Sense_Get_I_Grid_Inst();
		  float v_cc = Sense_Get_V_DC_Link();

		  PWM_AFE_Process_Background_Math(v_pg, v_cc); // Processamento passivo contínuo

		  /* 3. Máquina de Estados do Retificador (AFE Control) */
		  switch(afe_control_stage){
			  case 0: // STANDBY (DESCARGA DE SEGURANÇA)
				  HAL_GPIO_WritePin(SoftStart_GPIO_Port, SoftStart_Pin, GPIO_PIN_RESET);
				  PWM_AFE_PWM_Kill();
				  inverter_enable = 0;
				  PWM_Inverter_Update(0); // Força desligamento do Inversor
				  PWM_Set_Main_Contactor(0); // Abre a rede

				  if (afe_user_enable) afe_control_stage = 1; // Ativação pelo UI
				  break;

			  case 1: // PRÉ-CARGA (CONTROLO TÉRMICO)
			  	  system_fault = 0;
			  	  // 1. Fecha o contactor principal da rede (se ainda não estiver fechado)
			  	  PWM_Set_Main_Contactor(1);
  				  // 2. Executa a lógica que verifica a tensão e fecha o relé de Soft-Start
  				  PWM_Handle_SoftStart_Sequence(v_cc);
  				  // 3. Verifica se a tensão já atingiu o patamar seguro para avançar a máquina de estados
  				  if (v_cc > 35.0f) {
  					  afe_control_stage = 2; // Passa ao controlo de potência final
  				  }
  				  if (!afe_user_enable) {
                        PWM_Set_Main_Contactor(0); // Abre a rede se o utilizador desistir
                        afe_control_stage = 0;
                    }
  				  break;

			  case 2: // RETIFICAÇÃO ATIVA E DESPACHO
				  if (afe_control_enable) {
					  PWM_AFE_Run_PI_and_Hysteresis(i_pg);
					  PWM_Inverter_Update(inverter_enable); // Depende da UI do Inversor
				  } else {
					  PWM_AFE_PWM_Kill();
					  inverter_enable = 0;
					  PWM_Inverter_Update(0);
					  PWM_Set_Main_Contactor(0); // Abre a rede
				  }

				  if (!afe_user_enable && !afe_control_enable) afe_control_stage = 0;
				  break;
		  }
		  tim = 0; // Sinaliza fim de processamento do ciclo temporal
	  }

	  /* =========================================================
		 DOM�?NIO 3: INTERFACE E TELEMETRIA (10 Hz)
		 ========================================================= */
	  static uint32_t last_update = 0;

	  if (HAL_GetTick() - last_update > 100) // Delay não-bloqueante
	  {
		 last_update = HAL_GetTick();
		 Panel_Update_UI(system_fault);
		 Update_Interface(&huart3);

		 float temp_atual = Sense_Get_Heatsink_Temp();
		 PWM_Update_Cooling_Fan(temp_atual);
	  }
    /* USER CODE END WHILE */

    /* USER CODE BEGIN 3 */
  }
  /* USER CODE END 3 */
}

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
/* USER CODE BEGIN 4 */
//--------------------------------------------------------------------------
/* Interrupção Base do Sistema de Tempo (25 kHz via TIM1) */
void HAL_TIM_PeriodElapsedCallback(TIM_HandleTypeDef *htim) {
    if (htim->Instance == TIM1)
    	tim = 1;
}

/* Interrupção Assíncrona de Falha Eletrónica (Falha Ativa em Nível Lógico) */
void HAL_TIMEx_BreakCallback(TIM_HandleTypeDef *htim) {
    if (htim->Instance == TIM1 || htim->Instance == TIM8)
    	Emerg = 1;
}
//--------------------------------------------------------------------------
/* USER CODE END 4 */
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


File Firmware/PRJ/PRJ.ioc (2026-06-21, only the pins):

Mcu.UserName=STM32H755ZITx
PA0.GPIO_Label=IA
PA0.Signal=ADC1_INP16
PA3.GPIO_Label=IB
PA3.Signal=ADCx_INP15
PA4.GPIO_Label=SINE
PA4.Signal=COMP_DAC11_group
PA5.GPIO_Label=CONST
PA5.Signal=COMP_DAC12_group
PA6.GPIO_Label=IN1Brk
PA6.Signal=TIM8_BKIN
PB0.GPIO_Label=IN2N
PB0.Signal=TIM8_CH2N
PB1.GPIO_Label=IN3N
PB1.Signal=TIM8_CH3N
PB5.GPIO_Label=ST7789_SPI
PB5.Signal=SPI1_MOSI
PB6.GPIO_Label=ENClk
PB6.Signal=S_TIM4_CH1
PB7.GPIO_Label=ENDt
PB7.Signal=S_TIM4_CH2
PC0.GPIO_Label=VDC
PC0.Signal=ADCx_INP10
PC3_C.GPIO_Label=Temp
PC3_C.Signal=ADC3_INP1
PC6.GPIO_Label=FAN
PC6.Signal=S_TIM3_CH1
PC7.GPIO_Label=IN2
PC7.Signal=S_TIM8_CH2
PC8.GPIO_Label=IN3
PC8.Signal=S_TIM8_CH3
PC9.GPIO_Label=Back
PC9.Signal=GPIO_Output
PD0.GPIO_Label=SW
PD0.Signal=GPXTI0
PD11.GPIO_Label=SoftStart
PD11.Signal=GPIO_Output
PD12.GPIO_Label=CHOPPER
PD12.Signal=GPIO_Output
PD13.GPIO_Label=ST7789_RST
PD13.Signal=GPIO_Output
PD14.GPIO_Label=ST7789_DC
PD14.Signal=GPIO_Output
PD15.GPIO_Label=ST7789_CS
PD15.Signal=GPIO_Output
PD8.Signal=USART3_TX
PD9.Signal=USART3_RX
PE10.GPIO_Label=OUT2N
PE10.Signal=TIM1_CH2N
PE11.GPIO_Label=OUT2
PE11.Signal=S_TIM1_CH2
PE12.GPIO_Label=OUT3N
PE12.Signal=TIM1_CH3N
PE13.GPIO_Label=OUT3
PE13.Signal=S_TIM1_CH3
PE15.GPIO_Label=OUTBrk
PE15.Signal=TIM1_BKIN
PE8.GPIO_Label=OUT1N
PE8.Signal=TIM1_CH1N
PE9.GPIO_Label=OUT1
PE9.Signal=S_TIM1_CH1
PF11.GPIO_Label=IC
PF11.Signal=ADC1_INP2
PF7.GPIO_Label=VIn+
PF7.Signal=ADC3_INP3
PF9.GPIO_Label=IIn+
PF9.Signal=ADC3_INP2

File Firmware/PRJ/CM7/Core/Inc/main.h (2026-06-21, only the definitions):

#define VIn__Pin GPIO_PIN_7
#define VIn__GPIO_Port GPIOF
#define IIn__Pin GPIO_PIN_9
#define IIn__GPIO_Port GPIOF
#define VDC_Pin GPIO_PIN_0
#define VDC_GPIO_Port GPIOC
#define Temp_Pin GPIO_PIN_3
#define Temp_GPIO_Port GPIOC
#define IA_Pin GPIO_PIN_0
#define IA_GPIO_Port GPIOA
#define IB_Pin GPIO_PIN_3
#define IB_GPIO_Port GPIOA
#define SINE_Pin GPIO_PIN_4
#define SINE_GPIO_Port GPIOA
#define CONST_Pin GPIO_PIN_5
#define CONST_GPIO_Port GPIOA
#define IN1Brk_Pin GPIO_PIN_6
#define IN1Brk_GPIO_Port GPIOA
#define IN2N_Pin GPIO_PIN_0
#define IN2N_GPIO_Port GPIOB
#define IN3N_Pin GPIO_PIN_1
#define IN3N_GPIO_Port GPIOB
#define IC_Pin GPIO_PIN_11
#define IC_GPIO_Port GPIOF
#define OUT1N_Pin GPIO_PIN_8
#define OUT1N_GPIO_Port GPIOE
#define OUT1_Pin GPIO_PIN_9
#define OUT1_GPIO_Port GPIOE
#define OUT2N_Pin GPIO_PIN_10
#define OUT2N_GPIO_Port GPIOE
#define OUT2_Pin GPIO_PIN_11
#define OUT2_GPIO_Port GPIOE
#define OUT3N_Pin GPIO_PIN_12
#define OUT3N_GPIO_Port GPIOE
#define OUT3_Pin GPIO_PIN_13
#define OUT3_GPIO_Port GPIOE
#define OUTBrk_Pin GPIO_PIN_15
#define OUTBrk_GPIO_Port GPIOE
#define SoftStart_Pin GPIO_PIN_11
#define SoftStart_GPIO_Port GPIOD
#define CHOPPER_Pin GPIO_PIN_12
#define CHOPPER_GPIO_Port GPIOD
#define ST7789_RST_Pin GPIO_PIN_13
#define ST7789_RST_GPIO_Port GPIOD
#define ST7789_DC_Pin GPIO_PIN_14
#define ST7789_DC_GPIO_Port GPIOD
#define ST7789_CS_Pin GPIO_PIN_15
#define ST7789_CS_GPIO_Port GPIOD
#define FAN_Pin GPIO_PIN_6
#define FAN_GPIO_Port GPIOC
#define IN2_Pin GPIO_PIN_7
#define IN2_GPIO_Port GPIOC
#define IN3_Pin GPIO_PIN_8
#define IN3_GPIO_Port GPIOC
#define Back_Pin GPIO_PIN_9
#define Back_GPIO_Port GPIOC
#define SW_Pin GPIO_PIN_0
#define SW_GPIO_Port GPIOD
#define SW_EXTI_IRQn EXTI0_IRQn
#define ST7789_CLK_Pin GPIO_PIN_3
#define ST7789_CLK_GPIO_Port GPIOB
#define ST7789_SPI_Pin GPIO_PIN_5
#define ST7789_SPI_GPIO_Port GPIOB
#define ENClk_Pin GPIO_PIN_6
#define ENClk_GPIO_Port GPIOB
#define ENDt_Pin GPIO_PIN_7
#define ENDt_GPIO_Port GPIOB

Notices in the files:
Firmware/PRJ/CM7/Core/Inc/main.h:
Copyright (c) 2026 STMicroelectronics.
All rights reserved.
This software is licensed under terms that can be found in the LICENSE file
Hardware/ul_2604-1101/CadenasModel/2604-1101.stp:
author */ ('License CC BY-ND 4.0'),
